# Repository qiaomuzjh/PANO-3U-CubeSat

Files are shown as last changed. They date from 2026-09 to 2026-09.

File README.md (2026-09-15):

# 🛰️ PANO-3U CubeSat | 双鱼眼全景立方星 — 全套开源设计制造文件包

**3U CubeSat · 500 km SSO · 360°×180° dual-fisheye panoramic imaging · Full open-source design & manufacturing package**

> 一颗可以在车库里造出来的卫星:从需求规格、GB 生产图纸、参数化 STEP 模型、KiCad 工程、
> BOM/工艺/检验试验规范,到飞行操作手册与发射场安全数据包——全部开源。

**License: CC BY-NC 4.0** (署名-非商业性使用) · Author / 作者:**张嘉豪 (Zhang Jiahao)**

---

## ✨ 任务概览 / Mission

| 项目 | 规格 |
|---|---|
| 构型 | 3U(100×100×340.5 mm),Cal Poly CDS Rev.14,P-POD 兼容 |
| 任务 | 双鱼眼侧面对置 360°×180° 全景成像,输出 5760×2880 |
| 载荷 | 2× Sony IMX477 + M12 鱼眼 f1.4/F2.4 FOV≥195°(等距投影) |
| 视频 | 4K30(CAM0)+ 2.8K30(CAM1),双机硬同步 <1 ms |
| 轨道 | 500 km SSO(i=97.4°),设计寿命 ≥1 年 |
| 数传 | UHF 437 MHz,GFSK 57.6 kbps(裕量 10.7 dB),AX.25/KISS |
| 电源 | 72 片太阳阵 18.4 W BOL,4 通道 MPPT,2S2P 49 Wh |
| 姿态 | B-dot 消旋(17.3°/s→2°/s @2.3 h)+ 磁强计粗定姿 ±5° |
| 质量 | 2.83 kg(含 20% 裕量)| 结构基频 611 Hz | 全 SF≥28 |

## 📁 仓库结构 / Repository Layout

```
00_包总览/          标准符合性索引 · 配置基线 · 需求追溯矩阵 · 文件总索引
01_系统设计文件/    需求规格 · 设计说明书 · ICD · 电子规格书 · 结构/热/可靠性/EMC/FMEA
02_评审与质量/      设计评审 · 数据一致性核查 · 模型与数据检验
03_生产图纸_GB23页/  ★ 23 张 GB 机械制图生产图纸(PDF/PNG/SVG,含完整尺寸链与形位公差)
04_三维模型_STEP/    ★ 15 个参数化重建实体(零件 + 整星装配,AP214)
05_电气设计_KiCad/   板框模板 ×4 + 投板核对清单
06_物料清单/         PL-001 零件明细表(关键件分级)+ BOM v2 采购清单
07_生产与装配工艺/   制造总方案(里程碑)· 装配工艺规程(A1-A12 工序卡)
08_检验与试验/       检验与试验规范(GEVS 振动 + TVAC 热真空)
09_软件/             载荷软件(CM4)· OBC 固件(STM32)· 地面站(Python)+ 发布说明
10_发射与运营/       飞行操作手册 · 地面站手册 · 离轨方案 · 发射场安全数据包
99_归档/             原始设计资料 + 已替代示意图册(禁止用于生产)
```

## 🚀 快速开始 / Quick Start

- **想看这颗星长什么样** → `03_生产图纸_GB23页/PDF`(23 页)或 `04_三维模型_STEP/装配`
- **想复刻/教学** → `00_包总览/STD-000`(标准对照)→ `REQ-001`(需求)→ `07`(工艺)→ `08`(试验)
- **想学卫星工程** → 从 `SPC-001 设计说明书` 入手,配合 `ANA-001 仿真报告` 与 `TRC-001 追溯矩阵`
- **要发射?** → 完成 `REV-001` 开放项 C1-C6,按 `SAF-001` 对接发射商

## 📐 标准体系 / Standards

Cal Poly **CDS Rev.14** · NASA **GSFC-STD-7000B (GEVS)** · **NASA-STD-7001A** ·
**SpaceX Rideshare PUG** · **ECSS** E-ST-10-03C / Q-ST-30-11C · **GJB** 1027A / 151B / Z 299C / Z 35 ·
**ISO 24113**(碎片减缓)· **ITU/IARU**(频率协调)· UN 3481(电池运输)
→ 逐项对照见 `00_包总览/STD-000`

## ⚠️ 免责声明 / Disclaimer

所有数值为设计/仿真值;本包为教学与研究用途,飞行应用必须完成文档中列出的开放项
(FEA 复核、镜头实测、热真空试验、软件联调、频率许可),并通过发射商安全评审。
本作品按"现状"提供,不附带任何担保。

## 📄 许可证 / License

**CC BY-NC 4.0**(署名-非商业性使用 4.0 国际)
- ✅ 自由共享、修改、二次创作(教学/研究/个人)
- ❌ 不得用于商业目的
- 📌 必须署名:张嘉豪 及本仓库链接,并标注修改
- 完整文本见 [LICENSE](LICENSE) · [NOTICE](NOTICE)

Copyright © 2026 张嘉豪 (Zhang Jiahao)

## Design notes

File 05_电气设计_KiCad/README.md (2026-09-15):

# PANO-3U KiCad 工程 README(v2 / 投产核对版)

**版本:v2 / 2026-09** | KiCad 7.0+ 打开 `PANO-3U.kicad_pro`
**本版修正(相对 vB README):**
1. ~~TPS2553×4 电子保险丝~~ → **U20 = TPS2557(CM4 支路 3 A),U21-U23 = TPS2553**(原理图 vB 已正确,本 README 旧文案有误,已勘误);
2. 数传默认速率 **57.6 kbps**(链路裕量 10.7 dB;9.6 kbps 为备份速率)——固件 comm.c 默认参数同步修改;
3. 新增 `板框模板/`:四种板的 PCB-000 外形(.kicad_pcb,Edge.Cuts 已绘 90×90 四角 45° 切口 + 4×Ø3.2 安装孔),Layout 直接导入。

## 工程结构
| 文件 | 内容 |
|---|---|
| `PANO-3U.kicad_pro` | 工程文件 |
| `PANO-3U.kicad_sch` | 根图(层次化入口) |
| `eps.kicad_sch` | E8 EPS(U1-U4 LT3652 MPPT、U6 TPS54331、U20 TPS2557、U21-23 TPS2553、INA226×4) |
| `obc.kicad_sch` | E7 OBC(STM32F405、TPS3823、W25Q128、DS3231、MPU-9250、QMC5883L、DRV8837×3) |
| `comm.kicad_sch` | E9 UHF(Si4463、RA07H4452M 1W PA、PE4259、SAW、TCXO 30MHz) |
| `cm4_carrier.kicad_sch` | E2 CM4 载板(DF40C-100DP、双 22P CSI、TPS22965、microSD) |
| `PANO-3U.kicad_sym` | 项目符号库(18 个自定义符号) |
| `板框模板/` | PCB-000 外形模板 ×4(本版新增) |

## 投板前核对清单(必须逐条签署)
1. **自定义符号引脚映射**(18 个符号,引脚号为逻辑编号):
   - LT3652 → MSOP-12EP 实际封装(占位 DFN16 必须改);
   - STM32F405RGT6 → LQFP-64 实际引脚号;
   - RA07H4452M / PE4259 / Si4463 模块逐脚核对;
2. R/C/L/D/连接器使用 KiCad 官方库,天然正确;
3. 运行 **ERC** 全绿后再 Layout;
4. 电源完整性:5V 走线 ≥0.5 mm(或敷铜),VBAT ≥0.8 mm;MIPI 差分 100Ω 等长 ±0.5 mm;
5. **U20 必须 TPS2557**:BOM/位号/丝印三处核对,防止与 TPS2553 混贴(两者封印相似);
6. CM4 双相机:CAM1 为 2-lane,相机 2 的 D2/D3 已断开;4K30 带宽实测不足则切换 CM5/USB3 备选;
7. 板框以 `板框模板/*.kicad_pcb`(PCB-000,与生产图纸册 P15 一致)为准;
8. 网表与 `BOM v2.xlsx`(E 系列)、`ELE-002 规格书` 三处一致后方可投板。

## 与其他文件的协调
原理图网络名/位号 ↔ BOM v2(E 系列)↔ ELE-002 规格书 逐条对应;改动任何一处四处同步
(另两处:生产图纸册 ELE-403 器件布局、固件信号命名)。

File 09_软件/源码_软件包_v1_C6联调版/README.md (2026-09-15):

# PANO-3U 软件包

版本 B / 2026-09 — 双鱼眼全景立方星完整软件系统

## 组成

```
软件包/
├── docs/通信协议规范.md        板间链路 + UHF上下行 帧格式/指令/错误码
├── payload_cm4/               ★ 星上载荷软件 (CM4, Python3, Raspberry Pi OS)
│   ├── main.py                主程序/状态机/systemd服务入口
│   ├── camera.py              双鱼眼同步采集 (picamera2, RAW+H.265)
│   ├── stitch.py              全景拼接核心 (等距投影+重叠区加权融合)
│   ├── storage.py             文件登记/分块/断电保护/空间回收
│   ├── link.py                OBC链路 (HDLC帧+CRC16, 流式解码)
│   ├── config.py              参数表 (可在轨更新)
│   └── tests/                 6项单元测试 (全部通过)
├── obc_firmware/              ★ OBC飞控固件 (STM32F405, C/HAL/FreeRTOS)
│   └── Core/{Src,Inc}/        main/fsm/adcs/comm/payload_mgr/驱动/日志
└── ground_station/            ★ 地面站 (Python3)
    ├── ground_station.py      主控 (对接Direwolf KISS)
    ├── receiver.py            AX.25解析 + 下行包解码
    ├── image_assemble.py      图像分块重组/断点续传/断电恢复
    ├── stitch_ground.py       地面精拼接 (特征匹配+多频段融合)
    ├── calibrate.py           出厂标定工具 (旋转棋盘格法)
    └── pass_predict.py        过境预测 (TLE+SGP4)
```

## 部署

**CM4 星上**：
```bash
sudo cp -r payload_cm4 /opt/pano3u/
sudo systemctl enable /opt/pano3u/pano3u-payload.service
# calibration.json 由出厂标定生成后放入 /opt/pano3u/
```

**OBC**：见 `obc_firmware/README.md`（CubeMX/PlatformIO 构建）。

**地面站**（Linux + RTL-SDR 或 UHF 电台声卡）：
```bash
pip install opencv-python numpy skyfield pyserial
direwolf -t 0 -r 48000 -   # 或接电台声卡
python3 ground_station/ground_station.py --kiss 127.0.0.1:8001
```

## 研制测试顺序

1. `pytest payload_cm4/tests/` —— 协议/存储/拼接单元测试（PC 上跑）
2. 桌面联调：CM4 实物 + USB-串口 ↔ 跑通 OBC 协议的 PC 模拟器
3. 双相机标定：`calibrate.py` 生成 `calibration.json`
4. 星地链路拉距：SDR 发信标 → 地面站解码验证
5. 整星联试：振动/热真空后复测拍摄与下传

## 关键性能

- 拍照→全景图生成：约 8 s（5760×2880，含双 RAW 采集）
- 视频：双路 4K30 H.265，码率 25 Mbps/路
- 下行：单过境 ≈400 KB（9.6 kbps×8 min×70% 效率），5 MB 全景图约 12 个过境
- 断点续传：块级位图 + 选择重传，支持跨过境断点

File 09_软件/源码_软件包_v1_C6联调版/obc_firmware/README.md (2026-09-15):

# OBC 固件构建说明

## 工具链
- STM32CubeMX 6.x (生成HAL骨架) + arm-none-eabi-gcc
- 或 PlatformIO: `platform = ststm32`, `board = genericSTM32F405RG`

## 目录
```
Core/Src/
  main.c          主程序+任务
  obc_fsm.c       模式状态机
  adcs.c          B-dot消旋
  comm.c          AX.25+下行队列
  payload_mgr.c   CM4协议+拍摄计划
  link_proto.c    板间帧编解码
  drivers.c       QMC5883L/MPU9250/INA226/DS18B20/热控/天线
  misc_drivers.c  DRV8837/看门狗/W25Q128日志
Core/Inc/         对应头文件 (位号/寄存器地址与电子系统规格书一致)
```

## 构建
```bash
# CubeMX方式: 用 PANO-3U.ioc 生成工程后替换Core/Src
arm-none-eabi-gcc -mcpu=cortex-m4 -mthumb -mfpu=fpv4-sp-d16 -mfloat-abi=hard \
  -O2 -DUSE_HAL_DRIVER -DSTM32F405xx ...
# PlatformIO方式:
pio run -e obc
```

## 关键配置
- FreeRTOS: 4任务 (comm>adcs>hk>payload), 堆栈见main.c
- HSE 8MHz → PLL → 168MHz, SysTick 1kHz
- UART1=9600(通信板), UART2=115200(CM4), 均DMA+空闲中断
- Flash: 前64KB bootloader(预留IAP), 应用从0x08010000

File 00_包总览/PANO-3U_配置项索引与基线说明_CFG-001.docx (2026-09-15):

PANO-3U 双鱼眼全景立方星

(3U CubeSat · 500km SSO 全景成像任务)

配置项索引与基线说明

配置项清单 · 图样目录 · 基线定义 · 替代关系

文档编号 | PANO-3U-CFG-001
版本 | A(功能基线→生产基线)
编制日期 | 2026-09
编制 / 审核 / 批准 | / /
分发 | 制造 / 质量 / 采购 / 试验

# 1 基线定义

①功能基线 = REQ-001(SPC-001 §2);②分配基线 = 各分系统设计文件(ELE-002/STR-001/THR-001/REL-001/EMI-001);③生产基线 = 生产图纸册 23 页(A 版)+ BOM v2 + DXF v4 + STEP v2 + KiCad v2;④软件基线 = SW-001 标识的版本。任何基线更改走 REV-001 行动项流程并同步SPC-001 ↔ 图纸 ↔ BOM v2(四处同步原则)。

# 2 配置项清单(设计与制造)

配置项 | 版本/基线 | 形式 | 状态
生产图纸册 P1–P23 | A | PDF/PNG/SVG(A3) | 现行(生产放行)
DXF 加工文件 ×13 | v4 | DXF | 现行(与图纸一致,QA-001 D1)
STEP 模型 ×15(含整星装配) | v2 | STEP AP214 | 现行(MDV-001 检验通过)
KiCad 工程(4 板)+板框模板 | 原理图 vB / 板框 v2 | kicad_sch/kicad_pcb | 现行(ERC/符号映射见核对清单)
BOM v2 / PL-001 零件明细表 | v2 / A | xlsx | 现行
管理文件 MFG-001/QA-001/WI-001/QT-001 | v1.0 | docx | 现行
设计文件 SPC/REQ/ICD/ELE/STR/ANA/THR/REL/EMI/FMEA/REV/STD/OPS/DEB/GND/SAF | A/B | docx | 现行
软件(载荷/固件/地面站) | 见 SW-001 | 源码+构建物 | C6 联调版
仿真数据 CSV ×11 | v1 | csv | ANA-001 引用,随包归档

# 3 图样目录(Drawing List)

图号/页 | 名称 | 版本 | 状态
P1 ASM-001 | 总装配图 | A | 现行
P2–P13 | MEC-101/102/103A/103B/104/105/106/107/111/108/109/110 零件图 | A | 现行
P14 PLD-201 | 相机传感器板 | A | 现行
P15 PCB-000 | 电路板外形图(通用) | A | 现行
P16 BAT-001 | 电池舱组件装配图 | A | 现行
P17 PLD-001 | 相机模组组件装配图 | A | 现行
P18 ELE-001 | 电气堆栈组件装配图 | A | 现行
P19 SOL-001 | 太阳阵铺贴图 | A | 现行
P20 ANT-001 | 天线组件装配图 | A | 现行
P21 SEP-001 | 分离开关与 RBF 机构装配图 | A | 现行
P22 WIR-001 | 线束图与下线表 | A | 现行
P23 ENV-001 | 整星包络检验图 | A | 现行

# 4 替代关系(旧文件处置)

旧文件 | 处置 | 替代
《3U 全景立方星全套图纸 v3/v4》PDF(18 页)与《总装图纸 v4》(3 页) | 归档(01_原始设计资料) | 生产图纸册 23 页(A 版)
《线稿示意图册》22 页(ASM-000~WIR-701 示意版) | 降级为“参考图册”,仅供装配示意,不得用于加工 | 生产图纸册 23 页
原 BOM 清单 v1 | 归档 | BOM v2 / PL-001
原 md 格式说明书/规格书/评审/结构/仿真报告 | 归档 | SPC-001/ELE-002/REV-001/STR-001/ANA-001
原 STEP 模型(简化版) | 归档 | STEP v2(参数化重建,MDV-001 检验)

PANO-3U-CFG-001 配置项索引与基线说明 A(功能基线→生产基线)

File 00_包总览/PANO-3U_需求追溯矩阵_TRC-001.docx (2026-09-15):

PANO-3U 双鱼眼全景立方星

(3U CubeSat · 500km SSO 全景成像任务)

需求追溯矩阵

SYS/分系统需求 → 图纸/模型/软件 → 工序 → 验证

文档编号 | PANO-3U-TRC-001
版本 | A(需求→设计→制造→验证 全链路)
编制日期 | 2026-09
编制 / 审核 / 批准 | / /
分发 | 制造 / 质量 / 采购 / 试验

# 1 追溯矩阵

需求 | 设计证据 | 制造证据 | 验证证据 | 状态
SYS-01 包络 | P1/P23;STEP ASM-001 | WI-001 A12 | QT-001 §4.2(检具) | ✅
SYS-02 质量 | BOM v2;STEP 体积(MDV-001 §1) | A12 称重 | QT-001 §4.4(≤2.9 kg) | ✅
SYS-03 频率 | P2/P3/P6;STEP 导轨 | A1/A2/A8 | QT-001 §5.1(衰减<5%) | ✅(FEA=C1)
SYS-04 结构环境 | P2/P3/P6;STR-001 | KCP-5 marking | QT-001 §5.1(GEVS) | ✅
SYS-05 全景 | P17/P19;SW 载荷 | A6 锁焦(KCP-3) | 出厂标定+拼接验证 | ✅
SYS-06 视频 | ELE-002 §4;SW 载荷 | A3 堆栈/A7 FPC | C6 实测 | △(C6)
SYS-07 轨道 | ANA-001 S1 | — | A | ✅
SYS-08 测控 | P18/P20/P22;ELE-002 §5 | A11 敷设;WIR-001 | QT-001 §4.12 拉距 | △(B 阶段)
SYS-09 姿态 | P18;ELE-002 §3;SW 固件 | A3;W11 下线 | ANA-001 S5 + 在轨 | ✅(A)
SYS-10 能源 | P19;THR-001;BOM E15-E20 | A5(KCP-8)/A10(KCP-4) | QT-001 §4.7 + TVAC | ✅(A)
SYS-11 热控 | THR-001;BOM E17/E34 | A5 MLI/加热 | QT-001 §5.2 TVAC | △(C4)
SYS-12 发射安全 | P21/P3;SEP-001 | A9 停检点(KCP-7) | QT-001 §4.6 四状态 | ✅

# 2 追溯纪律

需求新增/变更:REQ-001 变更单 → 设计文件与图纸同步 → 本矩阵更新 → QT-001 验证项更新;矩阵每阶段评审(REV-001)复核一次,未闭环项自动成为 REV 行动项。

PANO-3U-TRC-001 需求追溯矩阵 A(需求→设计→制造→验证 全链路)

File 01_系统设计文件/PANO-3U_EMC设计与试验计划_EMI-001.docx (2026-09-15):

PANO-3U 双鱼眼全景立方星

(3U CubeSat · 500km SSO 全景成像任务)

EMC 设计与试验计划

设计与安装规则 · 自兼容试验 · 频率协调

文档编号 | PANO-3U-EMI-001
版本 | A(对照 GJB 151B / MIL-STD-461G)
编制日期 | 2026-09
编制 / 审核 / 批准 | / /
分发 | 制造 / 质量 / 采购 / 试验

# 1 EMC 设计控制

①电源:各支路限流+输入 TVS;DC-DC 开关频率远离 UHF 中频;母线入口 π 滤波;②结构:单点接地(结构地经 1 MΩ+10 nF 浮接),搭接电阻<2.5 mΩ;③信号:MIPI 差分 100Ω 屏蔽,敏感器线远离 PA/磁力矩器;④磁:磁力矩器工作与磁强计采样分时(QMC 采样窗口避开 PWM 沿);⑤PA 发射时 OBC/相机由屏蔽罩+软件滤波兜底。

# 2 试验计划(阶段 B,对照 GJB 151B / MIL-STD-461G)

项目 | 方法参照 | 限值/判据
CE102 电源传导发射 | GJB 151B CE102 | 母线传导≤曲线限值;无开关噪声超标
RE102 电场辐射发射 | GJB 151B RE102 | PA 关/开对比;除载波外无杂散超标
CS115/116 脉冲与传导敏感 | GJB 151B | 不引起复位/数据错误
RS103 电场辐射敏感 | GJB 151B | 50 V/m 下功能正常(过顶裕度内)
自兼容专项 | PA 发射时 IMU/磁强计/温度读数比对 | 读数无跳变或可软件滤波恢复
整星星地拉距 | 发射场/校园 | 57.6 kbps 误包率<1%(10.7 dB 裕量)

# 3 频率协调

下行 437.0 MHz 处于业余卫星频段(435-438 MHz);发射前完成 IARU 频率协调申请与中国无线电管理机构(或发射商要求之牌照方)许可;上行采用业余段对应频点;发射前提交调制参数/带宽/EIRP/轨道给协调方存档。

PANO-3U-EMI-001 EMC 设计与试验计划 A(对照 GJB 151B / MIL-STD-461G)

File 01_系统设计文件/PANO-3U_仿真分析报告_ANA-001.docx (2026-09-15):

PANO-3U 双鱼眼全景立方星

(3U CubeSat · 500km SSO 全景成像任务)

仿真分析报告

质量/轨道/能源/热/结构/ADCS/链路/光学(S0–S7)

文档编号 | PANO-3U-ANA-001
版本 | A(对应设计版本 C)
编制日期 | 2026-09
编制 / 审核 / 批准 | / /
分发 | 制造 / 质量 / 采购 / 试验

# 0 方法声明

全部仿真为 Python 数值计算(轨道:二体+J2;磁场:倾斜 11.5° 偶极;热:6 节点集总,5 s 步长;结构:一维梁 FE;姿态:四元数动力学,dt=0.5 s),输入取自版本 C 设计文件。本报告用于方案定值与验证,正样阶段以高保真工具(STK/IGRF/ESATAN/ANSYS)复核(开放项)。

# S0 质量特性

指标 | 数值 | 备注
干质量 | 2 359 g | 25 项分部件几何重建(旧 BOM 估算 1 730 g 低估 27%)
发射质量 | 2 831 g(+20%) | CDS 上限 4 800 g,裕量 41%
质心 | (0.0, −0.2, 146.7) mm | 低于几何中心 23.6 mm(重力梯度有利)
惯量 | Ixx=0.0168/Iyy=0.0173/Izz=0.00271 kg·m² | —

# S1 轨道与过顶

500 km SSO(i=97.40°,T=94.5 min),每日 15.2 轨;最坏日食 β=0 时 35.7 min/轨(37.8%),β≥65° 时降至 14.5 min。北京站 7 天过顶 20 次(2.9 次/天),平均 6.2 min、最大 7.3 min。

# S2 能源(最坏 β=0,EOL 0.90,MPPT 0.95)

项 | 结果
单轨平均发电 | 3.41 W → 日 81.9 Wh
日耗电 | 30 Wh(4 次拍摄+过顶数传占空)
裕量 | 2.73×(β 0°~60° 扫描均 ≥2.7×)
7 天时域 SOC | 80%~100%,最低 DoD 20%(限 80%)✅

# S3 热(六节点集总,48 h)

工况 | 核心 | 面板 | 电池 | 判定
热(全日照+载荷 2W) | 15~20°C | 15~19°C | 15~20°C | ✅
冷(原设计:裸装+2W) | −24~3°C | −26~3°C | −21~6°C | ✗ 低于充电禁限
冷(修订:MLI+3W) | −20~8°C | −22~7°C | −12~+8°C | △ 占空 79%,TVAC 收口

设计修订已回写:电池包 MLI、加热 2→3 W、LT3652 NTC 0°C 禁充;BOM v2 已同步(QA-001 A2/A3)。

# S4 结构

梁 FE:f1=611 Hz;随机 GEVS:Miles 39.2 gRMS(3σ=118 g);准静态 10 g。裕度:导轨压应力 SF=76/屈曲≫100/F2 剪切 28/电池支架 36/相机支架 52(详 STR-001)。

# S5 ADCS(B-dot 消旋)

初始 10°/s/轴(|ω|=17.3°/s)→ 2.3 h 降至 ≤2°/s,24 h 后 0.13°/s;磁偶限幅 0.2 A·m²;全景任务(≤2°/s)成立,无需反作用轮。

# S6 通信链路

速率 | 灵敏度 | 最低裕量 | 日吞吐 | 判定
9.6 kbps | −120 dBm | 18.7 dB | 0.8 MB | 备份速率
57.6 kbps(默认) | −112 dBm | 10.7 dB | 4.6 MB | ✅ 35 快视图/天
115.2 kbps | −109 dBm | 7.7 dB | 9.2 MB | 可选

整星级发现:4K 视频(375 MB/min)物理上无法经 UHF 下传;存 512 GB 卡仅下抽帧;S 频段升级(1 Mbps→85 MB/天,+¥2 500)列为选装。

# S7 光学

等距投影角分辨率 15.8 px/°(全视场恒定),拼接输出 5760×2880=16.0 px/° ✅;重叠环带 82.5°~97.5°(13% 全球面,≥8° 匹配下限 1.9×)✅;GSD:星下 0.55 km/px,60° 离轴 2.21 km/px(辅助功能)。

# S8 汇总判定

项 | 结论
质量/包络 | ✅ 2.83 kg,CDS 合规
轨道/过顶 | ✅ 2.9 次/天
能源 | ✅ 2.73×,SOC≥80%
热 | △ 修订后满足(MLI+3W+NTC),TVAC 收口
结构 | ✅ f1=611 Hz,SF≥28
ADCS | ✅ 2.3 h 消旋
链路 | △ 57.6 kbps 满足运营;视频需 S 频段选装
光学 | ✅ 指标闭环

CSV 原始数据(11 个文件)随原始资料归档。

PANO-3U-ANA-001 仿真分析报告 A(对应设计版本 C)

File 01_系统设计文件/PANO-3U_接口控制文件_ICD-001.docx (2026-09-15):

PANO-3U 双鱼眼全景立方星

(3U CubeSat · 500km SSO 全景成像任务)

接口控制文件(ICD)

机械 / 电气 / 射频 / 地面段 四类接口

文档编号 | PANO-3U-ICD-001
版本 | A
编制日期 | 2026-09
编制 / 审核 / 批准 | / /
分发 | 制造 / 质量 / 采购 / 试验

# 1 机械接口(M-ICD)

接口 | 定义 | 公差/要求
星-P-POD | 4 导轨 8.5×8.5×340.5;中心距 91.5×91.5;端板 100×100 分离面 | 导轨 0/−0.05;共面度≤0.1;分离弹簧行程按 CDS
星-相机 | 侧板窗 Ø26+0.1/0;镜头外伸 6.0(限 6.5);三级定位链同轴≤Ø0.05 | 窗位 (170±0.05, 41.5±0.05)
星-电池 | MEC-106 抱箍内腔 37×23.4;18650 Ø18.6×65.4 | 内阻配对≤20 mΩ 差
星-太阳阵 | 贴片区 3-92×71,起点 14/121/228,边距 6 | 贴片位置±0.5
星-天线 | MEC-109 装 +Z 端板 ±Y 边;卷收态不超包络 | 臂长 344±2

# 2 电气接口(E-ICD)

## 2.1 J1 堆栈总线(全 40 位)

Pin | 信号 | Pin | 信号 | Pin | 信号 | Pin | 信号
1 | GND | 2 | GND | 3 | VBAT | 4 | VBAT
5 | +5V | 6 | +5V | 7 | +3V3 | 8 | +3V3
9 | I2C1_SDA | 10 | I2C1_SCL | 11 | UART_OBC_TX | 12 | UART_OBC_RX
13 | UART_CM4_TX | 14 | UART_CM4_RX | 15 | CAN_H | 16 | CAN_L
17 | DEPLOY_EN | 18 | ANT_STAT | 19 | SAFE_MODE | 20 | WD_KICK
21 | MAG_X_PWM | 22 | MAG_Y_PWM | 23 | MAG_Z_PWM | 24 | HEAT_EN
25 | SW_STAT | 26 | PAYLOAD_EN | 27-40 | GND/预留

## 2.2 外接连接器

代号 | 连接器 | 走向 | 引脚定义
J1 | 2×20P 车针 | 四板堆栈 | 上表
J2 | JST-XH2P | 分离开关链→EPS | Pin1=SW 链+,Pin2=−
J3 | JST-XH2P | RBF 座→EPS | 同上
J4-J7 | JST-XH2P | ±Y/±X 太阳阵→EPS | Pin1=+,Pin2=−
J8 | JST-XH2P | EPS→CM4 5V | Pin1=+5V,Pin2=GND
J9 | JST-SH6P | EPS→加热+温控 | 加热±×2、温控×2、预留
J12 | SMA-KY | COMM→天线(经巴伦) | 50Ω

## 2.3 功率分配

支路 | 限流 | 负载
CM4+相机 | 3 A(TPS2557) | CM4 5V 输入;拍摄峰值 9.45 W
OBC | 1 A(TPS2553) | STM32+敏感器 ≈0.4 W
PA | 1.5 A(TPS2553) | UHF 发射 3.75 W 输入
加热 | 1 A(TPS2553) | 3 W×2(占空 79%)

# 3 射频接口(RF-ICD)

项 | 定义
频率 | 437.0 MHz(业余卫星段,以 IARU 协调为准)
调制/速率 | GFSK;57.6 kbps(默认)/9.6 kbps(备份)
EIRP | ≈29 dBm(1 W PA − 线损 + 天线增益)
多普勒 | ±10 kHz(500 km SSO,过顶补偿)
极化/指向 | 线极化;全向偶极,过顶无需精确指向
禁射 | 分离后 DEPLOY_DELAY(30/45 min 按发射商)

# 4 地面段接口(G-ICD)

项 | 定义
站址 | 北京(40°N,116°E),仰角门限 10°,过顶 2.9 次/天,平均 6.2 min
设备 | 12 dBi 八木+旋转器+RTL-SDR/电台+Direwolf KISS 127.0.0.1:8001
数据流 | KISS→receiver.py 解码→image_assemble 重组→stitch_ground 拼接
测控协议 | AX.25 UI 帧;上行指令双重确认+错误码(通信协议规范.md)

PANO-3U-ICD-001 接口控制文件(ICD) A

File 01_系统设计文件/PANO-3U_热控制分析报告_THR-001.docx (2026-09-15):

PANO-3U 双鱼眼全景立方星

(3U CubeSat · 500km SSO 全景成像任务)

热控制分析报告

工况 · 修订定值 · TVAC 判据

文档编号 | PANO-3U-THR-001
版本 | A(六节点集总网络)
编制日期 | 2026-09
编制 / 审核 / 批准 | / /
分发 | 制造 / 质量 / 采购 / 试验

# 1 模型与假设

六节点集总网络:核心(OBC/EPS/CM4 组合体)、+Y/−Y 面板(太阳片)、+X/−X 面板、电池组;步长 5 s、仿真 48 h。辐射基准:阳极氧化 ε≈0.85(黑色)/0.1(抛光);导热路径:CM4→导热垫(1 mm,6 W/m·K)→散热块→铜柱→端板;电池组→支架→侧板。热耗:待机 0.78 W / 拍摄 9.45 W / 数传 3.75 W;外热流按 500 km SSO β 角扫描。

# 2 工况与结果

工况 | 核心 | 面板 | 电池 | 判定
热工况(全日照+载荷 2 W) | 15~20°C | 15~19°C | 15~20°C | ✅ 无过热
冷工况(最大日食+SAFE,原设计裸装+2 W) | −24~3°C | −26~3°C | −21~6°C | ✗ 低于 0°C 充电禁限
冷工况(修订:MLI+3 W 加热) | −20~8°C | −22~7°C | −12~+8°C | △ 占空 79%,日照段恢复充电

# 3 设计修订(已回写设计与 BOM v2)

①电池组外覆 MLI 多层隔热(双面镀铝聚酯 10 层,有效发射率≈0.03),引线穿孔衬套;②加热膜 2→3 W×2(聚酰亚胺,5 V),与 KSD9700(5°C 闭合/8°C 断开)硬件串联;③LT3652 NTC(10 kΩ B=3380,贴电池)配置 0°C 充电禁止;④镜头侧日照局部可超 +45°C:镜座/镜头选耐温材料,TVAC 验证(开放 C4)。

# 4 TVAC 验收判据(试验阶段 B)

项 | 判据
压力 | ≤1×10⁻³ Pa
循环 | −20~+50 °C ×4 循环,高低温各保持 2 h(变化率<1°C/10 min 判稳定)
电池温度 | 冷工况 ≥0°C(充电允许)或证实禁充逻辑生效;热工况 ≤+45°C
功能 | 每个高温/低温平台完成一次双机拍摄;数传一次
后检 | 复压后外观/绝缘≥10 MΩ/紧固 marking 复查

PANO-3U-THR-001 热控制分析报告 A(六节点集总网络)

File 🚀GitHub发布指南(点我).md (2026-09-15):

# 🚀 GitHub 发布操作指南(张嘉豪专用,三选一)

本机环境:**未安装 git**,本机无你的 GitHub 凭证(QQ 浏览器的登录态无法传给命令行),
所以仓库内容我已 100% 备好在 `桌面\PANO-3U-CubeSat`,你只需按下面三种方式**任选其一**完成发布。

推荐顺序:**方式 A(GitHub Desktop,最简单)> 方式 B(网页直传)> 方式 C(命令行)**

---

## 方式 A:GitHub Desktop(推荐,10 分钟)

1. 下载安装 **GitHub Desktop**:https://desktop.github.com
2. 打开 GitHub Desktop → `File` → `Add local repository` → 选择
   `C:\Users\qiaomu\Desktop\PANO-3U-CubeSat`
   → 会提示"not a repository",点 `Create a Repository`:
   - Name: `PANO-3U-CubeSat`
   - 勾选 "Keep this code private" **不要勾**(要开源)→ `Create Repository`
3. 顶部菜单 `Repository` → `Push` → 首次会弹登录:
   - `Sign in to github.com` → 浏览器授权(你 QQ 浏览器已登录,直接点 Authorize)
   - 若浏览器默认不是 QQ 浏览器:在 GitHub Desktop 设置里 `Options → Advanced`
     选择默认浏览器,或复制授权链接到 QQ 浏览器打开
4. 推送前先去网页建仓库:浏览器打开 https://github.com/new
   - Repository name: `PANO-3U-CubeSat`
   - 选 **Public** → 不要勾任何初始化选项(README/LICENSE 都已备好)→ `Create`
   - 回到 GitHub Desktop → `Repository` → `Push` → `Publish repository`
     (取消勾选 "Keep this code private")→ 完成 ✅

---

## 方式 B:网页直传(零安装,~5 分钟)

1. 浏览器打开 https://github.com/new
   - Name: `PANO-3U-CubeSat`;选 **Public**;**全部取消勾选**(README/LICENSE/gitignore 我已备好)→ `Create repository`
2. 在新仓库页点 **"uploading an existing file"**
3. 把 `桌面\PANO-3U-CubeSat` 里的**全部内容**(不是文件夹本身)拖入上传框
   - ⚠️ 网页上传单文件限 25 MB、总数最多 100 个文件——
     本包 234 个文件超限,建议:先拖 00~10 的文件夹(共 ~200 个),
     `99_归档` 与 `09_软件/源码` 若提示过多,分 2-3 批拖入
4. 底部 Commit message 填 `PANO-3U 全套开源设计制造文件包 v1.0` → `Commit changes` → 完成 ✅
   (更省事还是用方式 A/C)

---

## 方式 C:命令行 git(装 Git 后最通用)

1. 安装 Git for Windows:https://git-scm.com/download/win(一路下一步)
2. **Win+R → `cmd`**,逐条执行(用户名/邮箱换成你的):

```bat
cd /d C:\Users\qiaomu\Desktop\PANO-3U-CubeSat
git init
git add .
git commit -m "PANO-3U 全套开源设计制造文件包 v1.0"
git branch -M main
```

3. **配置代理**(你挂了梯子,git 不走系统代理,必须单独配;端口看你梯子软件,
   Clash 默认 7890,v2rayN 默认 10809):

```bat
git config --global http.proxy  http://127.0.0.1:7890
git config --global https.proxy http://127.0.0.1:7890
git config --global user.name  "Zhang Jiahao"
git config --global user.email "你的GitHub邮箱"
```

4. 浏览器打开 https://github.com/new → Name: `PANO-3U-CubeSat` → Public →
   **取消勾选 README/LICENSE/gitignore** → Create

5. **用 PAT 登录推送**(命令行不能用浏览器登录态,需要令牌):
   - 打开 https://github.com/settings/tokens → `Generate new token (classic)`
   - 勾选 `repo` 权限 → 生成后**立即复制**(只显示一次)
   - 回到 cmd:

```bat
git remote add origin https://github.com/你的用户名/PANO-3U-CubeSat.git
git push -u origin main
```

   - 弹出登录窗口:用户名=你的 GitHub 用户名,密码=粘贴刚才的 **PAT 令牌**
   - 推送完成 ✅ 打开仓库页即可看到全部文件

---

## 📋 发布前最后检查(已替你核过)

- ✅ 无任何密钥/令牌/个人隐私信息(签署栏均为空白占位)
- ✅ 版权与署名:NOTICE/LICENSE 已写"张嘉豪 (Zhang Jiahao)",CC BY-NC 4.0 全文
- ✅ 频率/发射安全内容均为公开标准知识;地面站坐标仅到城市级
- ⚠️ 开源即公开:BOM 里的采购价格、地面站位置(北京)如介意可自行删除后推送
- ⚠️ NC 许可:GitHub 开源无碍;但 **CC BY-NC 不是 OSI 开源许可证**,严格说是
  "免费公开+非商用";若日后希望商用友好,可另加 `LICENSE-CODE`(GPL/MIT)双许可

## 建议仓库设置

- Description: `PANO-3U open-source 3U CubeSat — full design & manufacturing package (GB drawings / STEP / KiCad / docs) CC BY-NC 4.0`
- Topics: `cubesat` `satellite` `open-source-hardware` `space` `panoramic-camera` `step` `kicad`
- 若单文件超 25 MB 报错(不太会,最大 6.5 MB),或日后模型变大,再考虑 Git LFS

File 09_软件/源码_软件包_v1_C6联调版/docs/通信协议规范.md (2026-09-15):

# PANO-3U 通信协议规范

版本 B / 2026-09

## 1. 板间链路（OBC ↔ CM4 载荷计算机）

- 物理层：UART，115200 8N1，3.3V 电平，经堆栈总线 J1（Pin 13/14）
- 帧结构（HDLC 风格）：

```
[0x7E][CMD:1B][LEN:1B][PAYLOAD:0~255B][CRC16-CCITT:2B][0x7E]
转义: 载荷中出现 0x7E→0x7D 0x5E；0x7D→0x7D 0x5D
```

### 指令表（OBC→CM4）

| CMD | 名称 | 载荷 | 说明 |
|---|---|---|---|
| 0x01 | PING | — | 心跳，CM4 须 1s 内回 ACK |
| 0x02 | TIME_SYNC | uint32 epoch | 时间同步 |
| 0x03 | SHOOT | uint8 burst, uint16 interval_s | 全景拍照（连拍张数/间隔） |
| 0x04 | VIDEO_START | uint16 duration_s, uint8 fps | 开始全景视频 |
| 0x05 | VIDEO_STOP | — | 停止录像 |
| 0x06 | TIMELAPSE | uint16 interval_s, uint16 count | 延时摄影 |
| 0x07 | GET_STATUS | — | 查询载荷状态 |
| 0x08 | FILE_LIST | uint16 offset | 文件清单（分页） |
| 0x09 | FILE_PREP | uint32 file_id | 准备下传某文件（返回分块表） |
| 0x0A | SHUTDOWN | — | 载荷安全关机（OBC 随后断 PAYLOAD_EN） |
| 0x10 | PARAM_SET | key:1B + value:4B | 参数设置（曝光/增益/编码码率等） |

### 应答（CM4→OBC）

| CMD | 名称 | 载荷 |
|---|---|---|
| 0x81 | ACK | 原CMD + status |
| 0x87 | STATUS | 见下 |
| 0x88 | FILE_LIST_RESP | count + [file_id:4B, size:4B, ts:4B]×N |
| 0x89 | FILE_PREP_RESP | file_id, total_chunks:2B, chunk_size:2B, file_crc32:4B |

STATUS 载荷（24B）：mode:1B, cam0_ok:1B, cam1_ok:1B, temp0:int8, temp1:int8, disk_free_mb:uint16, vbat_mv:uint16, shooting:1B, pending_files:uint16, uptime_s:uint32, last_err:1B, reserved:6B

## 2. UHF 下行链路（星→地）

- 物理层：437 MHz，GFSK 9600 bps，AX.25 UI 帧（HDLC 封装由 Si4463+OBC 软件完成）
- AX.25 地址：源=NOCALL-11（星），目的=NOCALL-0（地面），PID=0xF0

### 下行包类型（AX.25 Info 字段首字节为类型）

| 类型 | 名称 | 结构 | 时机 |
|---|---|---|---|
| 0x01 | 信标遥测 | [type][seq:2B][OBC遥测32B][CM4 STATUS 24B][CRC32] | 每 30s 周期性 |
| 0x02 | 文件块 | [type][file_id:4B][chunk_no:2B][total:2B][data:N][CRC32] | 过境时连续发送 |
| 0x03 | 文件清单 | 同 FILE_LIST_RESP | 应地面请求 |
| 0x04 | 事件日志 | [type][ts:4B][code:1B][data:8B] | 异常/模式切换时 |

### 断点续传与选择重传

- 文件分块：每块 200 字节，块内 CRC32 校验；
- 地面站按 file_id 收块，记录已收位图；
- 过境结束时地面站通过上行（AX.25 命令帧，需执照操作）或下一过境首包发送**缺失块清单**（位图压缩），星上补发；
- 单文件最多支持 65535 块（≈13 MB），全景图压缩后约 5 MB ≈ 25000 块，一过境（8 min @9.6kbps 有效吞吐约 400 KB）约 12 个过境传完。

### 上行（地→星）

| CMD | 名称 | 说明 |
|---|---|---|
| 0x21 | REQ_MISSING | file_id + 位图偏移 + 缺失块列表 |
| 0x22 | SET_MODE | 强制模式切换（双重确认） |
| 0x23 | SCHEDULE | 拍摄计划表上传（最多 32 条：[epoch, cmd, param]） |
| 0x24 | PARAM_SET | 同板间 0x10 |

## 3. 错误码

0x00 OK；0x01 相机0故障；0x02 相机1故障；0x03 存储满；0x04 存储I/O错误；0x05 编码器错误；0x06 温度超限；0x07 参数非法；0x08 链路超时

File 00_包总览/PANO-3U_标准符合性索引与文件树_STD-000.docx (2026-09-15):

PANO-3U 双鱼眼全景立方星

(3U CubeSat · 500km SSO 全景成像任务)

标准符合性索引与文件树

航天机构与商业航天公司标准对照 · 全套文件树

文档编号 | PANO-3U-STD-000
版本 | A
编制日期 | 2026-09
编制 / 审核 / 批准 | / /
分发 | 制造 / 质量 / 采购 / 试验

# 1 适用标准与符合性对照

标准/文件 | 发布方 | 适用范围 | PANO-3U 符合性证据
CDS Rev 14.1 (2022-02) | Cal Poly CubeSat Program | 3U 构型/尺寸/质量/分离界面/材料/轨道 | P23 包络检验图;SEP-001 分离链;QA-001 D 核查
GSFC-STD-7000B (GEVS) | NASA GSFC | 随机/正弦/热真空鉴定与验收量级与方法 | QT-001 §5(14.1 gRMS 三向、TVAC 四循环);STR-001 输入
NASA-STD-7001A | NASA | 声振试验 | QT-001(小卫星按机械传递随机为主)
NASA-STD-8739.x | NASA | 焊接/装配工艺(Workmanship) | WI-001(烙铁温度/点胶/压接规则)
SpaceX Rideshare Payload User’s Guide | SpaceX | CubeSat 随机振动≥MPE、分离速度 0.3~1.0 m/s、L-30 交付、紧固件表 6-3 | QT-001 量级选取;OPS-001 LEOP 时序;SAF-001
ECSS-E-ST-10-03C | ESA | 试验分类与判据 | QT-001 试验矩阵
ECSS-Q-ST-30-11C | ESA | FMEA 方法 | FMEA-001(S/O/D 评分)
GJB 1027A-2005 | 中国军标 | 运载器/航天器试验环境 | QT-001 对照引用
GJB 151B-2013 | 中国军标 | EMC 发射与敏感度 | EMI-001
GJB/Z 35 / MIL-STD-975 | — | 元器件降额 | REL-001 降额表
ISO 24113 / IADC-02-01 | ISO/IADC | 轨道碎片减缓(25 年规则) | DEB-001
FCC 47 CFR §25.114(5 年离轨) | 美国 FCC | 美国牌照 LEO 卫星 5 年离轨 | DEB-001(按牌照方适用)
ITU 无线电规则 第 9 条 / IARU | ITU/IARU | 435-438 MHz 业余卫星频率协调 | ELE-002 §5;LIC 频率协调
UN 3481 / IATA DGR | UN/IATA | 锂离子电池随设备运输(电池 SoC≤30% 空运规则) | SAF-001 运输章节

# 2 全套文件树(编号体系)

编号 | 文件 | 状态
SPC-001 | 详细设计说明书(需求 SR/SYS、定值、预算、ICD 索引) | A 版 ✅
REQ-001 | 系统需求规格(全量需求+验证矩阵) | 本包
ICD-001 | 接口控制文件(机械/电气/射频/地面) | 本包
ELE-002 | 电子系统设计规格书 | B 版 ✅
STR-001 | 结构力学校核报告 | B 版 ✅
ANA-001 | 仿真分析报告(S0-S7) | A 版 ✅
THR-001 | 热控制分析报告 | 本包
REL-001 | 可靠性预计与降额设计 | 本包
EMI-001 | EMC 设计与试验计划 | 本包
FMEA-001 | 失效模式与影响分析 | A 版 ✅
生产图纸册 | 23 页 GB 图纸(P1-P23) | ✅(经加工方意见补标)
BOM v2 | 全级物料清单(修正+采购属性) | ✅
MFG-001/QA-001/WI-001/QT-001 | 生产/核查/工艺/试验 | ✅
OPS-001 | 飞行操作手册(LEOP+在轨+离轨) | 本包
GND-001 | 地面站运行手册 | 本包
DEB-001 | 轨道碎片减缓与离轨方案 | 本包
SAF-001 | 发射场安全数据包 | 本包
01_原始设计资料 | 原版文件与 KiCad/STEP/仿真 CSV 归档 | ✅

引用:CubeSat Design Specification Rev 14.1(Cal Poly,2022-02);GSFC-STD-7000B GEVS(NASA,2021);SpaceX Rideshare Payload User’s Guide;NASA CSLI《CubeSat 101》。

PANO-3U-STD-000 标准符合性索引与文件树 A

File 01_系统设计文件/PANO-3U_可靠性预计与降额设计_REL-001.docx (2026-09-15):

PANO-3U 双鱼眼全景立方星

(3U CubeSat · 500km SSO 全景成像任务)

可靠性预计与降额设计

元件计数法 · 降额表 · 单粒子对策 · 冗余设计

文档编号 | PANO-3U-REL-001
版本 | A
编制日期 | 2026-09
编制 / 审核 / 批准 | / /
分发 | 制造 / 质量 / 采购 / 试验

# 1 任务剖面与可靠性目标

任务剖面:500 km SSO,1 年,轨道 5 470 圈,日食占空 ≤37.8%,发射段环境 GEVS;目标:任务期末系统可靠度 ≥0.80(不含发射风险)。

# 2 元件计数法预计(依据 GJB/Z 299C / MIL-HDBK-217F 思路)

单板/组件 | 主要器件数 | 预计失效率(10⁻⁶/h) | 备注
E8 EPS | ≈120 | ≈8.5 | 功率器件降额后
E7 OBC | ≈95 | ≈4.2 | 含敏感器
E9 UHF | ≈80 | ≈5.0 | PA 高应力
E2 CM4 载板 | ≈60 | ≈3.0(不含 CM4 本体)
电池组件 | — | ≈2.0 | BMS+连接
机构(天线/开关/热刀) | — | ≈3.5 | 动作件按循环折算
整星合计 | — | ≈26(不含 CM4/相机本体) | CM4/相机按商质件,寿命试验覆盖

按 λ=26×10⁻⁶/h,1 年(8 760 h)串联可靠度 e^(−λt)≈0.80,达目标;CM4 与相机为商质件,依赖抽验与地面老化筛选(72 h 老炼)。

# 3 降额设计(依据 GJB/Z 35 / MIL-STD-975)

类别 | 降额要求 | 本项目实施
电容电压 | ≤50% 额定 | 钽电容按母线 2 倍选取
电阻功率 | ≤50% 额定 | 限流/采样电阻按 2 倍功率
晶体管电流 | ≤75% 额定 | AOD510/IRLML6344 按 2 倍余量
IC 结温 | ≤110°C(商用) | 热设计结温 ≤70°C
继电器/开关触点 | ≤50% 额定电流 | 微动开关 3 A 触点,回路≤0.8 A

# 4 单粒子效应(SEE)与冗余策略

COTS 器件在 500 km LEO(倾角 97.4°)主要为质子引发 SEU;TID 年剂量约 1-3 krad(Si),1 年任务远低于 30 krad 摸底限(开放 C3)。对策:参数表与固件镜像双备份(W25Q128+eMMC)、看门狗 30 s 复位链、SAFE 模式自动恢复、通信指令 CRC+重传;存储采用磨损均衡与坏块管理。

# 5 冗余设计汇总

功能 | 冗余/备份 | 切换方式
参数存储 | W25Q128 + eMMC 双份 | 上电 CRC 校验择优
天线释放 | 热刀×2 双刀 | DEPLOY_EN 重试序列
加热 | 硬件温控+软件使能双保险 | KSD9700 硬件串联
太阳充电 | 四通道独立 MPPT | 旁路二极管隔离故障面
时间基准 | DS3231 RTC + MCU 内部时钟 | 遥测比对

PANO-3U-REL-001 可靠性预计与降额设计 A

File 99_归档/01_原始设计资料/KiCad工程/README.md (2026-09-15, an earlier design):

# PANO-3U KiCad 工程 README

**版本 B / 2026-09**　|　KiCad 7.0+ 打开 `PANO-3U.kicad_pro`

## 工程结构

| 文件 | 内容 |
|---|---|
| `PANO-3U.kicad_pro` | 工程文件（双击打开） |
| `PANO-3U.kicad_sch` | 根图：4 块板的层次化入口 |
| `eps.kicad_sch` | E8 EPS 电源板（47 元件：LT3652×4 MPPT、LTC4412 理想二极管、TPS54331 5V/3A、TLV70233、TPS2553×4 电子保险丝、INA226×4 遥测） |
| `obc.kicad_sch` | E7 OBC 主控板（22 元件：STM32F405、TPS3823 看门狗、W25Q128、DS3231、MPU9250、QMC5883L、DRV8837×3） |
| `comm.kicad_sch` | E9 UHF 通信板（Si4463 模块 + RA07H4452M 1W PA + PE4259 收发切换 + SAW 滤波 + 30MHz TCXO） |
| `cm4_carrier.kicad_sch` | E2 CM4 载板（CM4 连接器、双 22P 相机 FPC、TPS22965 负载开关、microSD） |
| `PANO-3U.kicad_sym` | 项目符号库（18 个自定义 IC 符号） |
| `sym-lib-table` | 库映射（已配置，勿删） |
| `预览图/` | 四张原理图预览 PNG（无需 KiCad 即可查看连接关系） |

## 设计约定

- **四块板对应四块独立 PCB**（各 90×90 mm、4 层、Tg150、沉金），经 J1 2×20P 堆栈总线互联；
- 网络连接方式为**网络标签**（label）连通：同名标签即同一网络，KiCad 中可直接生成正确网表；
- J1 引脚定义与《电子系统设计规格书》§0 完全一致，四块板的 J1 网络名逐一对应。

## ⚠️ 投板前必须完成的核对清单

1. **自定义符号引脚号为逻辑编号**（PANO-3U 库中 18 个符号）：Layout 前必须按器件数据手册把每个引脚号映射到正确封装焊盘，重点核对：
   - LT3652（MSOP-12EP 实际封装，图中 DFN16 占位需改）
   - STM32F405RGT6（LQFP-64 实际引脚号，符号内为逻辑序号）
   - RA07H4452M、PE4259、Si4463 模块
2. R/C/L/D/连接器使用 **KiCad 官方库符号**，引脚映射天然正确；
3. 打开工程后运行 **ERC**（检查 → 电气规则），全绿后再画板；
4. 电源完整性：5 V 走线 ≥0.5 mm 宽（或敷铜），VBAT ≥0.8 mm；MIPI 差分对 100 Ω 等长 ±0.5 mm；
5. CM4 双相机：CAM1 为 2-lane，原理图中相机 2 的 D2/D3 已按规格书要求断开（不连接），量产前需在树莓派平台实测 4K30 带宽，不足则按规格书备选方案（CM5 或 USB3 相机）切换。

## 与图纸/BOM 的一致性

本工程网络名、位号与 `PANO-3U_全级BOM清单.xlsx`（E 系列编号）和《电子系统设计规格书》逐条对应；改动任何一处请三处同步。

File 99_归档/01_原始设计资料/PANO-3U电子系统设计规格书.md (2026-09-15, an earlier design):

# PANO-3U 电子系统设计规格书（PCB 原理图设计依据）

**版本 B / 2026-09　|　深度：器件级连接关系 + 全部接插件引脚定义，可直接交 PCB 工程师画原理图与 Layout**

四块板统一规格：90×90 mm、4 层 FR4 Tg150、1 oz 铜、沉金；安装孔 4×Ø3.2（76×76 分布）；板间通过 2×20P 2.54 mm 镀金车针排针（J1，堆栈贯通总线）。层叠建议：Top（信号）/ GND / PWR / Bottom（信号）。

## 0. 堆栈总线 J1（2×20P）引脚定义——四块板统一

| Pin | 信号 | Pin | 信号 |
|---|---|---|---|
| 1 | GND | 2 | GND |
| 3 | VBAT（7.4 V） | 4 | VBAT |
| 5 | +5V | 6 | +5V |
| 7 | +3V3 | 8 | +3V3 |
| 9 | I2C1_SDA | 10 | I2C1_SCL |
| 11 | UART_OBC_TX | 12 | UART_OBC_RX |
| 13 | UART_CM4_TX | 14 | UART_CM4_RX |
| 15 | CAN_H（预留） | 16 | CAN_L（预留） |
| 17 | DEPLOY_EN（热刀使能） | 18 | ANT_STAT（展开遥测） |
| 19 | SAFE_MODE | 20 | WD_KICK |
| 21 | MAG_X_PWM | 22 | MAG_Y_PWM |
| 23 | MAG_Z_PWM | 24 | HEAT_EN |
| 25 | SW_STAT（分离开关状态） | 26 | PAYLOAD_EN |
| 27–40 | GND/预留 | | |

每块板 J1 只引出本板用到的网络，但**排针必须全位数贯通**（堆栈结构件）。

---

## 1. E8 EPS 电源板

### 1.1 功能框
太阳阵 4 面（11.4 V/0.45 A 每面）→ LT3652 ×4（独立 MPPT 充电）→ 汇流（LTC4412 理想二极管）→ 2S 电池组（经 BMS + 分离开关×3 + RBF）→ 母线 VBAT → TPS54331（5 V/3 A）→ TLV70233（3.3 V/2 A）。

### 1.2 器件级连接

**LT3652（U1–U4，每面一路）**
- VIN：太阳阵输入，10 µF 陶瓷 + 100 µF 钽；MPPT 设定：VIN_REG 分压至 11.4 V（R 网络：R1=604 kΩ / R2=60.4 kΩ）
- BAT 输出：8.4 V 浮充（2S Li-ion），充电电流设 0.5 A（R_SENSE=0.2 Ω）
- TIMER 接地（C/10 终止），NTC 接 10 kΩ B=3380 热敏电阻（贴电池）
- 四路输出各经 **LTC4412 + P-MOSFET（Si2343）** 理想二极管汇流至充电母线

**分离开关/RBF 链路**（位于电池正极路径）：BAT+ → BMS P+ → J2.1 → SW1 → SW2 → SW3 → J3 RBF → VBAT
- SW 为三微动开关常闭触点串联，滚轮被 P-POD 压紧时**闭合**（注意：发射态闭合但 RBF 断开；入轨弹开→接通）
- RBF：Ø6.35 插销机械保持常开微动断开，拔除→闭合

**DC/DC**
- TPS54331（U6）：VBAT→5 V/3 A，L=10 µH（饱和电流≥4 A），输出 22 µF×2
- TLV70233（U7）：5 V→3.3 V/2 A，或 TPS54331 第二路
- 各输出支路串 **TPS2553** 电子保险丝：5 V-CM4 限 3 A、3.3 V-OBC 限 1 A、相机限 1.5 A、加热片限 1 A

**遥测**：INA226 ×4（I2C1，地址 0x40/41/44/45）：VBAT 电压电流、5 V 电流、充电电流、电池电压

**接插件**
- J4/J5/J6/J7：JST XH-2P，太阳阵 ±X/±Y 输入（Pin1=+，Pin2=−）
- J2：JST XH-2P 至分离开关链路；J3：RBF 座
- J8：JST XH-2P，5 V→CM4 载板；J9：JST SH-6P 至加热片×2+温控×2

### 1.3 Layout 要点
功率回路（LT3652 SW 节点、电感、采样电阻）最短路径，远离 INA226 采样；太阳阵输入 TVS（SMBJ15A）；板边铺铜接结构地（单点，经 1 MΩ+10 nF）。

---

## 2. E7 OBC 板

### 2.1 器件与连接

**STM32F405RGT6（U1）**
- HSE 8 MHz 晶振 + 32.768 kHz；BOOT0 下拉 10 kΩ；NRST 接 TPS3823-33 看门狗输出
- SWD 调试口：2×5P 1.27 mm（J10），测试点引出
- **I2C1**（PB6/PB7，上拉 2.2 kΩ 至 3V3）：J1.9/10 → INA226×4、QMC5883L（0x0D）、MPU-9250（0x68）
- **UART1**（PA9/PA10）：J1.11/12 → E9 通信板（9600 8N1，AX.25 帧）
- **UART2**（PA2/PA3）：J1.13/14 → CM4 载板（115200 8N1，遥测/指令）
- **TIM1 CH1–CH3**（PA8/PA9 冲突→改用 PE9/PE11/PE13）：J1.21/22/23 → DRV8837 ×3 磁力矩器
- **GPIO**：PA0=HEAT_EN（J1.24），PA1=DEPLOY_EN（J1.17，高电平触发热刀 3 s 脉冲），PA5=ANT_STAT 输入（J1.18），PA6=SW_STAT 输入（J1.25），PA7=PAYLOAD_EN（J1.26），PB0=WD_KICK（J1.20，软件 1 Hz 翻转喂 TPS3823）
- **SPI2**（PB13–15）：W25Q128JV（U2，固件镜像+参数表备份）
- **1-Wire**（PC6，4.7 kΩ 上拉）：DS18B20 ×6 总线
- RTC：DS3231（I2C1 0x68 冲突→移至 I2C2 PB10/PB11），CR1220 备份电池

**电源**：J1 取 3V3，每 VDD 100 nF + 4.7 µF；VDDA 经磁珠+1 µF。

### 2.2 软件接口
- 遥测帧（1 Hz 记录，过境下传）：VBAT、各支路电流、6 路温度、姿态（磁强计/陀螺）、模式字、看门狗计数
- 指令：模式切换、拍摄计划上传、热刀释放（双重确认+延时）、参数表更新
- 安全模式：Vbat<6.6 V 或看门狗复位 → 关载荷/加热优先保电

---

## 3. E9 UHF 通信板

- **DRF4463 模块**（Si4463，433/437 MHz）：SPI 接 J1 扩展（经 OBC 转接或直接挂 SPI2 冲突→用 USART3 模拟/SPI1 PB3–5 + NSS PA15）；TXEN/RXEN 由 OBC GPIO 经 J1.27/28
- **PA**：RF2126 或 RA07H4452M（437 MHz 1 W），供电 5 V 经 TPS2553（限 1.5 A），TX 时使能
- **收发切换**：PE4259 SPDT；**SAW 滤波**：B39162 系列（437 MHz）于天线口
- **天线口**：SMA-KY（J12）→ RG178 → 天线；巴伦 1:1（绕线变压器）置于天线安装座侧
- 时钟：30 MHz TCXO（Si4463 配套，频偏 ≤±2 ppm——多普勒 ±10 kHz 内需）

---

## 4. E2 CM4 载板

- **CM4 插座**：2×100P 高密度座（Hirose DF40C-100DP）
- **相机**：CAM0/CAM1 22P 0.5 mm FPC 座（J20/J21，注意 CM4 上 CAM1 仅 2-lane→IMX477 用 CAM0(4-lane) 接相机 1 高分辨率模式，CAM1 需飞线 I2C 使能第二路——**工程实现要点：CM4 双相机需 device tree 同时使能 CAM0/CAM1，CAM1 为 2-lane，IMX477 4-lane 降 2-lane 带宽足够 4K30 需实测验证；备选方案：换 CM5 或使用 USB3 相机模组**）
- **供电**：5 V/3 A 经 J1.5/6 进入，板载 3.3 V（CM4 内部 PMIC 用 5 V）；TVS SMBJ5.0A
- **eMMC/启动**：CM4 4 GB/32 GB eMMC 版；nRPIBOOT 跳线座（烧录用）
- **接口至 OBC**：UART（GPIO14/15）电平直连 J1.13/14；GPIO17=PAYLOAD_EN 输入（低电平时 CM4 断电——经负载开关 TPS22965 控制 5 V）
- **存储**：microSD 卡座（J22，UHS-I）用于图像数据；eMMC 存系统
- **散热**：CM4 顶面导热垫（1 mm，6 W/m·K）→ 铝散热块 → 4×M3 铜柱 → 端板框架
- **实时性**：双相机同步——用同一 GPIO（GPIO4）输出硬件触发至两相机 FSIN（HQ 相机支持外触发焊接点），同步误差 <1 ms

---

## 5. 传感器与执行器接口

| 器件 | 接口 | 供电 | 备注 |
|---|---|---|---|
| MPU-9250 | I2C1 0x68 | 3V3 | 装于 OBC 板 |
| QMC5883L | I2C1 0x0D | 3V3 | 远离磁力矩器 ≥40 mm |
| DS18B20 ×6 | 1-Wire PC6 | 3V3 | 电池×2/相机×2/板卡×2 |
| DRV8837 ×3 | TIM1 CH1–3 | 5 V | 线圈电流 ≤0.8 A，串联限流电阻实测标定 |
| 加热片 ×2 | HEAT_EN→AOD510 | 5 V | 与 KSD9700 温控串联（硬件双保险） |
| 热刀 ×2 | DEPLOY_EN→IRLML6344 | VBAT | 3 s 脉冲，双刀冗余 |

## 6. 设计规则（Layout 通用）

1. 全部电解电容禁用品，用钽/陶瓷（航天可靠性）；
2. 去耦：每 IC 电源脚 100 nF 贴装距离 <2 mm；
3. 高速（MIPI、SPI>10 MHz）走线阻抗 50 Ω 控，MIPI 差分 100 Ω±10%、等长 ±0.5 mm；
4. 板边 3 mm 禁布（铜柱安装区）；安装孔接地过孔阵列；
5. 晶振包地；SWD/UART 测试点全引出；
6. 三防漆（可选）：装配联试后喷涂，连接器遮蔽。

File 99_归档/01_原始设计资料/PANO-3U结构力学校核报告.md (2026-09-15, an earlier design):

# PANO-3U 结构力学校核报告

**版本 B / 2026-09　|　方法：解析法（梁模型 + Miles 方程 + 螺钉强度），发射前须以 FEA 复核电测数据为准**

## 1. 输入条件

| 项 | 取值 | 来源 |
|---|---|---|
| 总质量 | 2.2 kg（含 25% 裕量） | 质量预算 |
| 包络 | 100×100×340.5 mm | CDS Rev.14 |
| 结构材料 | 6061-T6，E=68.9 GPa，ρ=2700，σy=276 MPa | MMPDS |
| 准静态 | 10 g（三向包络） | 典型搭载要求 |
| 随机振动 | GEVS 鉴定级 14.1 gRMS，PSD 平台 0.16 g²/Hz | GSFC-STD-7000 |
| 一阶频率要求 | ≥100 Hz | 避免与火箭耦合 |

## 2. 一阶频率（梁模型）

4 根 8.5×8.5 导轨并联抗弯，含移轴项（d=45.75 mm）：
I_total = 4×(8.5⁴/12) + 4×72.25×45.75² = **606,635 mm⁴**

- 悬臂模型（保守）：f₁ = (1.875²/2π)·√(EI/wL⁴) = **388 Hz**
- 简支模型（上限）：f₁ = **1090 Hz**
- 实际边界介于两者之间，即便按悬臂也 **3.9 倍于 100 Hz 要求** ✅

## 3. 准静态 10 g

| 校核项 | 载荷/应力 | 许用 | 安全系数 |
|---|---|---|---|
| 导轨轴向压应力 | 0.75 MPa | 276 MPa | 368 |
| 导轨压杆屈曲 | 临界 10,206 N vs 实际 54 N | — | 189 |
| 侧板面内应力（1.5 mm） | ≈12 MPa | 276 MPa | 23 |

## 4. 随机振动（Miles 方程，Q=10，fn=150 Hz 保守取值）

- 输出响应 **19.4 gRMS**，3σ 峰值 **58 g**
- 最不利集中质量：电池组 0.5 kg → 286 N 惯性力

## 5. 紧固件校核（随机振动 3σ 工况）

| 连接 | 单钉载荷 | 应力 | A2-70 许用 | 安全系数 |
|---|---|---|---|---|
| 电池支架 4×M3（剪切） | 71.5 N | 10.1 MPa | 310 MPa | 31 |
| 侧板 F2 沉头 M3×10（拉伸） | 8.6 N | 1.7 MPa | 450 MPa | 258 |
| 镜座 M2×4 | 7.1 N | 3.6 MPa | 450 MPa | 125 |

全部安全系数 **≥30**（含力矩预紧后仍充分）✅

## 6. 结论与遗留项

1. 结构静强度、稳定性、刚度（频率）、紧固件全部满足，裕量充分；
2. 本报告为解析法先行版。**发射服务商审查通常要求 FEA 报告**——建议用交付的 STEP 装配体在 ANSYS/ABAQUS 中做模态+随机振动分析复核（网格 2 mm，导轨接触面绑定，PCB 以质量点等效）；
3. 鉴定级振动试验后复测一阶频率（衰减 <5% 判合格）并全数检查螺钉见证标记。

---

## v4 补遗（设计评审后仿真复算）

1. **质量修正**：按几何体积重建的干质量为 2.36 kg（早期 BOM 估算 1.73 kg 低估了导轨/侧板实重），发射质量取 2.83 kg（+20% 裕量）。本报告各项载荷按质量线性放大 ≈10%，所有安全系数仍 ≥25，结论不变。
2. **基频修正**：计入侧板弯曲刚度后全截面 I=1.354×10⁶ mm⁴（原仅计导轨 0.607×10⁶），梁有限元（24 单元+集中质量）复算 **f1=611 Hz**（悬臂），比原解析值 388 Hz 更高，结论更宽裕。
3. **随机振动**：GEVS 包络下 Miles 响应 39.2 gRMS（3σ=118 g）；相机支架 M2×4 螺钉剪切 SF=52，电池支架 M3×4 SF=36，导轨压应力 SF=76，屈曲 SF≫100。
4. 数据文件见 `仿真数据/结构_强度裕度表.csv`。

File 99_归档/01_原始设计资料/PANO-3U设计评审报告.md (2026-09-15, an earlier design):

# PANO-3U 设计评审报告（错误与风险清单）

**版本 v1 / 2026-09　|　对象：版本 B 全套交付物（说明书、图纸 v3、DXF、STEP、KiCad、软件包、BOM）**
**结论摘要：发现 3 项阻断级错误、3 项高风险错误（全部已在版本 C / 图纸 v4 中关闭），7 项中低风险（2 项已修、5 项给出处置），6 项必须在投制/发射前由第三方或试验完成的开放项。**

---

## 一、阻断级错误（已修复，不修复则卫星不合规或无法总装）

### E1　相机装于 ±Z 端面——违反 CDS 且物理上无法成立 【已关闭】
- **问题**：CDS Rev.14 规定卫星端面（±Z）不允许任何凸起，且 P-POD 内多星叠放时端面直接接触。原设计镜头外伸端板 4 mm，超限。更根本的是：镜头若缩回端板内侧，195° 视场的边缘光线（97.5°）会被板厚遮挡——镜头节点埋入 2 mm 时 Ø22 孔只能通过 ±80°，FOV 永远达不到 195°。该方案在几何上就不成立。
- **处置**：相机改至 **±X 侧面**对置安装（CDS 允许侧面凸起 ≤6.5 mm，设计外伸 6.0 mm），新增 MEC-111 相机支架、MEC-103A 相机面板（Ø26 窗 + 4×M2），±X 面太阳阵 20 片减为 16 片（整星 72 片、18.4 W BOL、日发电 74 Wh，裕量 2.5× 仍充足）。
- **已修订文件**：说明书 §1.2/§2/§3.1/§5、图纸 v4 的 S1/S2/S5/S8、新增 S18、DXF×3、STEP 装配体与预览图、BOM。

### E2　分离开关逻辑接反——卫星会在火箭舱内带电 【已关闭】
- **问题**：原文档"装入 P-POD 压紧→触点闭合"。RBF 销在发射前必须拔除，此后若开关闭合，卫星在舱内即上电，**直接违反 CDS 禁上电条款，会被发射商拒载**。
- **处置**：3 只开关统一改为 SPDT **常闭（NC）接法：压紧＝断开（舱内断电，与 RBF 无关），弹出＝闭合（分离后自动上电）**；RBF 保留为地面操作期的独立第二重断电（插入＝断）。
- **已修订文件**：说明书 §4.3（含勘误说明）、BOM E21/E22 备注。

### E3　90×90 mm 电路板/隔板与导轨几何干涉 【已关闭】
- **问题**：内部净宽仅 83 mm（100 − 2×8.5），90 mm 见方的板四角（|x|>41.5 且 |y|>41.5 区域）与导轨实体冲突，按原图根本无法装入。
- **处置**：所有 PCB 与 MEC-105 隔板**四角切 45° 缺口**（去除 |x|>41 且 |y|>41 角区，净间隙 ≥0.5 mm；安装孔 76×76 分布不受影响）。
- **已修订文件**：说明书 §4.1、MEC-105 DXF、STEP 装配体（所有板卡带缺口重建）。

---

## 二、高风险错误（已修复）

### E4　CM4 支路负载开关选型超限 【已关闭】
TPS2553 限流上限 1.7 A，而 CM4 支路设计 3 A。**已改 TPS2557**（0.5–5 A，同 SOT-23-6 封装），KiCad EPS 页 U20 与 BOM E8 已同步；U21–U23（≤1.5 A 支路）保留 TPS2553。

### E5　相机 2 的 4K30 视频在带宽上不可行 【已关闭，指标调整】
CM4 的 CAM1 仅 2-lane CSI（约 2 Gbps），4056×3040@30 RAW10 需 3.7 Gbps。**指标调整为：相机 1（CAM0，4-lane）4K30，相机 2 为 2.8K30 或全分辨率 13 fps**；拍照双机均全分辨率不受影响。说明书 §1.1/§3.2 已改。若必须双 4K30，需升级 CM5（CAM1 变 4-lane）——成本 +¥300 级别，列为可选项。

### E6　M12 鱼眼镜头与 HQ 相机接口不匹配 【已关闭】
HQ 相机为 CS 接口。已增加 **M12→CS 转接环（E33，×2）**，并要求装配后以实距靶复测后截距再锁焦。BOM、图纸 S8、说明书 §3.1 已同步。

---

## 三、中低风险项

| 编号 | 问题 | 等级 | 处置 |
|---|---|---|---|
| R1 | 地面站 receiver.py 把 KISS 帧当含 FCS 原始帧解析，`frame[16:-2]` 会误删 2 字节载荷 | 中（功能 bug） | **已修**：KISS 模式取 `frame[16:]`，回归测试 6/6 通过 |
| R2 | main.py 状态包"运行时长"字段误发纪元秒 | 低 | **已修**：改用单调时钟计时 |
| R3 | MPU-9250 已停产（EOL） | 中 | BOM 标注替代型号 BMI270+IST8310，二选一即可 |
| R4 | 展开后的 UHF 天线振子进入全景边缘视场 | 低 | 不遮挡主体；地面拼接掩膜已能处理，接受 |
| R5 | SAFE 模式原设计关闭加热回路，夜间电池可能低温 | 中 | **已修**：说明书 §5 改为 SAFE 下电池加热保持使能 |
| R6 | CDS 要求"分离后延时禁射频"的时长不同发射商取 30/45 min | 低 | 固件中已是参数（`DEPLOY_DELAY_S`），按发射商要求改数值即可 |
| R7 | 相机改侧面后，±X 面太阳阵减为 16 片 | 低 | 能源复核 72 片/74 Wh/裕量 2.5×，成立（见 §五验证） |

## 四、开放项（非错误，但必须在投制/发射前完成）

1. **FEA 有限元复核**：现结构校核为解析法（f1=388 Hz、屈服 SF≥189 等），发射商普遍要求 ANSYS/NASTRAN 报告——这是流程要求，不是设计缺陷。
2. **镜头实物验证**：f=1.4 mm 标品的真实 FOV、畸变曲线与等距投影偏差须采购样片实测；>3% 偏差时用 5 阶多项式建模（标定管线已支持）。
3. **辐照评估**：全部为 COTS 器件，未做 TID/SEE 分析。1 年以内 LEO 任务通常可接受，建议关键页（OBC 固件、存储）依赖已有的 W25Q128 冗余 + 看门狗复位链，必要时补 30 krad 级 TID 摸底。
4. **热真空试验验证**：单节点热分析为粗估（镜头侧日照区局部可超 +45 °C），以 TVAC 四循环实测为准。
5. **EMC/无线电台执照**：437 MHz 发射需办理业余或业务频率许可；整星 EMC 自兼容测试（PA 发射时 IMU/磁强计读数跳变）未做。
6. **软件在环硬件联调**：`payload_read_chunk()` 目前仍是占位实现（需按 OBC↔CM4 实际 UART 对接联调）；HDLC 位填充在固件中为简化实现，联调时按 Si4463 数据手册补齐。两者均已在代码注释和协议文档中显式标注。

## 五、关键复核数据

| 项目 | 结果 | 判定 |
|---|---|---|
| 链路预算 437 MHz / 500 km / 1 W / 9.6 kbps | 接收 −95 dBm vs 灵敏度 −120 dBm，裕量 **25 dB** | ✓ |
| 能源（v4 后 72 片） | 日发电 74 Wh vs 日耗 30 Wh，**2.5×** | ✓ |
| 相机视场几何（侧装） | 外伸 6.0 ≤ 6.5 mm；边缘光线掠过板面，掩膜可处理 | ✓ |
| 端面凸起 | v4 后端面无任何凸起 | ✓ CDS |
| PCB↔导轨间隙 | 缺口后 ≥0.5 mm | ✓ |
| 载荷软件回归 | pytest **6/6 通过**（修复后复测） | ✓ |
| 质量预算 | 修订净增 ≈25 g，2.19 kg ≤ 2.2 kg 目标 | ✓ |
| 成本 | 硬件 ≈¥20,699，整星 ≈¥4.57 万（不含发射） | ✓ |

## 六、版本 C（v4）修订文件清单

说明书版本 C、图纸 v4（18 页：替换 S1/S2/S5/S8、新增 S18）、DXF 13 个（MEC-103→103A/103B、105 加缺口、新增 MEC-111）、STEP 装配体与 MEC-111 单件 + 预览图 v4、KiCad（U20→TPS2557、README 注记）、BOM（4 处改 + E33 新增）、软件包（receiver.py、main.py 两处修复）。

**评审结论**：阻断级与高风险问题已全部闭环；在完成第四节 6 项开放项（其中 FEA、热真空、镜头实测为硬性门槛）之前，可投入结构件与 PCB 打样，**不建议直接投产飞行件**。

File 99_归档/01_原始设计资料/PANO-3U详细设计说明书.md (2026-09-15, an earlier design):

# PANO-3U 双鱼眼全景立方星 详细设计说明书（工程实施版）

**版本 B / 2026-09　|　深度：逐零件、逐螺钉、逐孔位，可直接投制**

配套文件：
- 三维模型：`STEP模型/`（10 个零件 STEP + 1 个整星装配体 STEP，可导入 SolidWorks/UG/FreeCAD）
- 软件包：`软件包/`（载荷软件/OBC固件/地面站/通信协议）
- 结构校核：`PANO-3U结构力学校核报告.md/.docx`
- 电路设计：`PANO-3U电子系统设计规格书.md/.docx`
- 图纸册：`图纸/3U全景立方星全套图纸_v4评审修订版.pdf`（18 张 A3）
- 加工文件：`图纸/DXF加工文件/`（13 个 DXF，可直接发 CNC/激光切割/PCB 厂）
- 物料清单：`PANO-3U_全级BOM清单.xlsx`（机加件/紧固件/电气电子/成本汇总 4 表）

---

## 第一部分　总体

### 1.1 任务与指标

3U 立方星（100.0×100.0×340.5 mm，Cal Poly CDS Rev.14），双鱼眼侧面对置全景成像，500 km SSO，全景输出 5760×2880；视频 4K30（相机1）+ 2.8K30（相机2），拍照双机全分辨率 4056×3040。**数传口径（v4 仿真定值）：UHF 9.6 kbps 日吞吐仅 0.8 MB，默认升速至 57.6 kbps（链路裕量仍 ≥10.7 dB，日吞吐 4.6 MB，下遥测+快视图+选定压缩照片）；4K 视频存 512 GB 卡（可存 1365 min）仅下抽帧，如需视频级下传需选装 S 频段发射机**，总质量 2.83 kg（几何重建干质量 2.36 kg + 20% 增长裕量；v4 评审发现早期按 BOM 估算的 1.73 kg 低估了导轨/侧板实重约 27%，已按解析体积修正；CDS 3U 上限 4.8 kg，裕量充足）。质心 z=147 mm（几何中心下方，重力梯度有利），硬件成本 ≈2.1 万元。

### 1.2 布局（沿 Z 轴，0 为 −Z 端面）

| Z 区间 (mm) | 内容 |
|---|---|
| 0–30 | −Z 端板（分离开关/RBF 界面） + 堆栈底座 |
| 30–123 | 电子堆栈：UHF 通信板 → EPS 板 → 隔板 → OBC 板 → CM4 载板（PC/104 式 M3 铜柱互联） |
| 123–227 | 电池舱：2×MEC-106 支架抱箍 4×18650（2S2P），两侧对称（±Y 侧），加热片+测温 |
| 150–200（±X 侧面） | **相机模组 1/2 对置于 ±X 侧板**，镜头朝 ±X 外伸 ≤6.0 mm（CDS 侧面凸起限值 6.5 mm 内） |
| 227–340.5 | +Z 舱段（走线/余量）+ +Z 端板 |

---

## 第二部分　机械设计（逐零件）

### 2.1 机加件清单（10 种，详见 BOM 表"机加件"）

| 图号 | 名称 | 材料/厚度 | 数量 | 单件质量 | 关键要求 |
|---|---|---|---|---|---|
| MEC-101 | +Z 端板 | 6061-T6 t=2.0 | 1 | 46 g | 相机基准面，沉孔与通孔同轴度≤0.05 |
| MEC-102 | −Z 端板 | 6061-T6 t=2.0 | 1 | 48 g | 分离开关孔位公差 ±0.05（CDS 界面） |
| MEC-103A | 侧板-相机面（±X） | 6061-T6 t=1.5 | 2 | 92 g | Ø26 相机窗 + 4×M2 攻丝；沉孔朝外 |
| MEC-103B | 侧板-普通面（±Y） | 6061-T6 t=1.5 | 2 | 96 g | 贴片区平面度≤0.2，沉孔朝外 |
| MEC-104 | 导轨 | 6061-T6 | 4 | 52 g | 直线度≤0.05/340，接触面 Ra≤1.6 |
| MEC-105 | 中部隔板 | 6061-T6 t=1.5 | 3 | 28 g | 导电氧化，减重孔 R4 |
| MEC-106 | 电池支架（U 型） | 6061-T6 t=1.5 | 2 | 35 g | 折弯件，抱箍 2 节 18650 |
| MEC-107 | 相机镜座 | 6061-T6 车件 | 2 | 18 g | M14×0.5 与镜头配作，止口 Ø22H7 |
| MEC-111 | 相机支架（L 型） | 6061-T6 t=2.0 | 2 | 16 g | 镜座与传感器板一体定位，装于侧板内侧 |
| MEC-108 | 分离开关支架 | 6061-T6 t=1.2 折弯 | 1 | 12 g | 3 只微动开关对准 −Z 端板孔 |
| MEC-109 | 天线安装座 | 6061-T6 | 2 | 10 g | 含热刀绕线柱 |
| MEC-110 | 压线卡 | 6061-T6 | 10 | 1.5 g | 线束固定，间距 ≤80 mm |

### 2.2 端板孔位坐标表（基准：板中心，单位 mm，±0.05）

**通用孔（±Z 端板相同）**

| 编号 | X | Y | 规格 |
|---|---|---|---|
| H1–H4 | ±45.75 | ±45.75 | Ø3.4 通孔（导轨端面螺钉 F1 穿入） |
| H5–H12 | ±25 | ±44 及 ±44 | ±25 | Ø3.2 通孔 ×8（辅助/扎线/内部支架） |
| H13–H16 | ±38 | ±38 | Ø3.2 通孔 ×4（堆栈铜柱 F6） |
| C1 | 0 | 0 | 60×30 通孔（走线减重，R4 圆角） |
| ~~L1 / M1–M4~~ | — | — | **v4 已取消**：相机改至 ±X 侧面，端板恢复为完整板面（仅保留 C1 走线孔），刚度提升 |

**−Z 端板追加**

| 编号 | X | Y | 规格 |
|---|---|---|---|
| S1 | +30.00 | −45.75 | Ø4.4 通孔（分离开关 1） |
| S2 | −30.00 | −45.75 | Ø4.4 通孔（分离开关 2） |
| S3 | +45.75 | 0.00 | Ø4.4 通孔（分离开关 3） |
| R1 | −45.75 | +30.00 | Ø6.3 通孔（RBF 销） |

### 2.3 侧板孔位（基准 A=左端面，B=下边缘，单位 mm）

- 端部辅助孔 H1–H4：(12, 16.5)、(12, 66.5)、(328.5, 16.5)、(328.5, 66.5)，Ø3.2；
- 导轨固定孔 K1–K10：X = 30/90/170/250/310 × Y = 6/77，Ø3.2 通孔 + **外表面 Ø6×90° 沉孔**（F2 沉头螺钉与板面齐平，避免侧向凸起超限）；
- 过线孔 P1（仅 MEC-103B）：(170, 41.5)，Ø6（太阳阵引线入内，加护套）；
- **MEC-103A 相机窗**：(170, 41.5)，Ø26 通孔 + 内侧孔口 0.3×45° 去毛刺；周圈 4×M2 攻丝深 4，位于 (170±12, 41.5±12)，用于 MEC-111 支架（F14）；
- 外表面贴片区 3 段 92×71（起始于 X=14/121/228），贴片区**不氧化**（裸铝导电氧化）；MEC-103A 中段贴片让位于相机窗，太阳阵 16 片布局（见图纸 S10B）。

### 2.4 导轨（关键件，×4）

- 截面 8.5×8.5（+0/−0.05），全长 340.5±0.1，两端倒角 C0.5（P-POD 导入）；
- 端面 M3 攻丝深 10（距端面 6，两端各 1）→ F1 螺钉；
- 两侧面 M3 攻丝深 6，位于 X=30/90/170/250/310（与侧板 K1–K10 对应）；
- 接触面硬质阳极氧化 ≥25 µm、Ra≤1.6，**氧化后禁止再加工**；全长直线度≤0.05，扭曲≤0.05，端面垂直度≤0.05。

### 2.5 紧固件总表（共 ≈150 颗，详见 BOM 表"紧固件与胶接"）

| 编号 | 规格 | 数量 | 力矩 | 防松 | 位置 |
|---|---|---|---|---|---|
| F1 | M3×8 内六角圆柱头 A2-70 | 8 | 1.0 N·m | Loctite 243 | 端板↔导轨端面（4 角×2 端） |
| F2 | M3×6 内六角沉头 A2-70 | 40 | 1.0 N·m | Loctite 243 | 侧板↔导轨侧面（4 面×2 轨×5 点） |
| F3 | M3×6 盘头 + 弹垫 | 20 | 1.0 N·m | 弹垫 | 堆栈板/隔板/开关支架 |
| F4 | M3×15 双通铜柱 | 8 | 手紧+1/4 圈 | 243 | CM4 载板↔OBC 层距 |
| F5 | M3×12 双通铜柱 | 8 | 手紧+1/4 圈 | 243 | OBC↔EPS、EPS↔通信板层距 |
| F6 | M3×10 双通铜柱 | 4 | 手紧+1/4 圈 | 243 | 堆栈底座 |
| F7 | M2.5×8 盘头 + 弹垫 | 8 | 0.5 N·m | 弹垫 | 相机传感器板（4/机） |
| F8 | M2×6 沉头 | 8 | 0.3 N·m | 243 | 镜座↔MEC-111 支架（4/座） |
| F14 | M2×8 盘头 + 弹垫 | 8 | 0.3 N·m | 243 | MEC-111 支架↔MEC-103A 侧板（4/机） |
| F9 | M3×8 盘头 + 弹垫 | 8 | 1.0 N·m | 弹垫+F13 螺母 | 电池支架↔隔板 |
| F10 | M2×5 沉头 | 6 | 0.3 N·m | 243 | 天线座/开关支架 |
| F11–F13 | M3 平垫 ×40 / 弹垫 ×28 / 尼龙锁紧螺母 ×8 | — | — | — | 配用 |

**装配铁律**：所有螺纹连接涂 Loctite 243（自锁螺母除外）；力矩螺丝刀使用前校准；拧紧后做漆笔见证标记；对角顺序分两次拧紧（50%→100%）。

---

## 第三部分　载荷（双鱼眼全景相机）

### 3.1 光学设计定值

- 传感器：Sony IMX477，4056×3040，像元 1.55 µm，感光面 6.29×4.71 mm；
- 镜头：M12×0.5，**f=1.4 mm**，F2.4，FOV≥195°（对角），等距投影 r=f·θ——由像圆半径 2.356 mm 与 θ_max=97.5° 反算 f=1.38 mm，取 1.4 mm 标品，采购时**向供应商索取畸变曲线表**确认等距投影（偏差 >3% 则在标定中以 5 阶多项式建模）；
- 角分辨率 15.6 px/°；拼接输出 5760×2880 equirectangular；双机对置重叠区 15°（≥8° 匹配下限的 1.9 倍）；
- 滤光：650 nm IR-cut（Ø8×0.55）贴于镜座后端面；
- 装配基准链：镜头 → 镜座 MEC-107（止口 Ø22H7 配 MEC-111 沉孔）→ 支架 MEC-111 → MEC-103A 侧板（窗孔同轴度≤0.05）——单链三级，误差可控；
- 安装：双机对置于 ±X 侧板中心（Z=170），光轴沿 ±X；**镜头前端面外伸 ≤6.0 mm，满足 CDS 侧面凸起 ≤6.5 mm**；端面（±Z）无任何凸起；
- 镜头接口：HQ 相机为 CS 口，加 M12→CS 转接环（E33）后拧入 M12 鱼眼；转接后按实距靶复测后截距并锁焦；
- 调焦：实距标定靶 1.5 m，中心 MTF 最优点锁焦，Loctite 401 三点点胶，静置 24 h 后复测。

### 3.2 标定与拼接管线

1. 出厂：旋转棋盘格法，每相机 ≥30 姿态，解内参（f、cx、cy、k1–k4）与双机外参（R,t），写入星上参数表（JSON，OBC 与 CM4 双备份）；
2. 星上：双机硬同步触发（<1 ms）→ RAW 采集 → ISP → H.265 存 microSD（相机1：4K30，CAM0 4-lane；相机2：2.8K30 或全分辨率 13 fps，CAM1 2-lane 带宽约 2 Gbps 上限）；抽 1/16 分辨率快视图；
3. 地面：等距投影半球展开 → 重叠区 ORB 特征匹配 + 光流亚像素对齐 → 多频段融合 → 5760×2880 输出；
4. 在轨修正：利用重叠区恒星匹配每 30 天校正外参漂移。

---

## 第四部分　电气电子（逐板卡）

### 4.1 板卡与堆栈

堆栈自下而上（−Z→+Z）：**E9 UHF 通信板 → F5 铜柱 → E8 EPS 板 → MEC-105 隔板 → F5 铜柱 → E7 OBC 板 → F4 铜柱 → E2 CM4 载板**；板间 2×20P 镀金车针排针（E23）贯通总线；所有 PCB 90×90 mm，**四角切 45° 缺口（去除 |x|>41 且 |y|>41 角区，避让 8.5 mm 导轨，净间隙≥0.5 mm）**，4×Ø3.2 安装孔（76×76 分布），4 层 FR4 Tg150 1 oz 沉金；MEC-105 隔板同规缺口。

| 板卡 | 核心器件 | 关键设计 |
|---|---|---|
| E7 OBC | STM32F405RGT6 + TPS3823 看门狗 + DS3231 RTC + W25Q128 | 30 s 看门狗；遥测记录；磁控算法 |
| E8 EPS | LT3652×4（每面独立 MPPT 充电通道） + INA226×4 + LTC4412 + TPS2557（CM4 支路 3 A）/TPS2553×3（其余支路） | 母线 5 V/3 A、3.3 V/2 A；支路电子保险丝 |
| E9 通信 | DRF4463（Si4463 成品模块）+ 1 W PA + SAW | 437 MHz，9.6 kbps GFSK，AX.25 |
| E2 CM4 载板 | CM4 插座 + 双 22P CSI + 5 V 输入 + UART/I2C 转接 | CM4 导热垫→铜柱→框架散热 |

### 4.2 线束表（W1–W14，详见图纸 ELE-402）

电源 22AWG、信号 28AWG（均 PTFE/M22759 级）；RF 用 RG178+SMA；相机用 FPC 22P/0.5 异面排线（200/300 mm 贴铜箔屏蔽）；连接器全部带锁（JST XH/SH）。**布线规则**：电源/信号/RF 分束，间距 ≥10 mm，每 80 mm 一只压线卡 MEC-110，连接器插好后点 GD414 硅橡胶应力释放。

### 4.3 分离与 RBF 安全回路

**BAT+ → BMS → SW1 → SW2 → SW3 → RBF → EPS 主输入**（全串联，任一断开即全星断电）。3 只 SPDT 滚轮压杆式微动开关装于 MEC-108 支架，滚轮对准 −Z 端板 Ø4.4 孔，**一律接常闭（NC）触点：装入 P-POD 后滚轮被导轨压入 → 触点断开 → 全星断电（此时 RBF 已拔除也满足 CDS 禁上电要求）；入轨弹射分离后滚轮弹开 → 触点闭合 → 自动上电启动**。RBF 销在地面操作期间提供独立第二重断电保障（发射前拔除）。**（v4 修正：v3 及之前版本“压入→闭合”的描述逻辑相反，在舱内 RBF 拔除后将导致星上带电，违反 CDS Rev.14 §3.3.4，已更正为 NC 接法。）**

---

## 第五部分　电源 / 热 / 姿态（计算定值）

- 太阳阵：±Y 面 20 片 + ±X 面 16 片（让位相机窗）= 72 片 Maxeon Gen3 切割片（22.6×34 mm，0.256 W/片 BOL），±Y 面 20S1P（Vmp=11.4 V）、±X 面 16S1P（Vmp=9.1 V，均在 LT3652 输入范围内）→ 整星 18.4 W BOL，OAP 3.4 W，日发电 ≈74 Wh vs 日耗电 ≈30 Wh（裕量 2.5×）；MPPT 采用 LT3652×4（每面独立通道）；SS34 旁路二极管每 8 片 1 只；3M 966 贴片；
- 电池：NCR18650B×4 2S2P，49 Wh，日食放电深度 7%；加热片 2 W（KSD9700 5°C 闭合/8°C 断开）；
- 功率：待机 0.78 W / 拍摄 9.45 W / 数传 3.75 W；日能耗 ≈30 Wh « 日发电 ≈130 Wh；
- 热（v4 六节点瞬态仿真定值）：热工况全星均衡 15~20°C，无过热风险；**冷工况（最大日食季+SAFE）裸装电池会降至 −21°C，低于 0°C 充电禁限** → 设计修订：电池包加 MLI 多层隔热 + 加热功率 2 W→3 W（占空 79%），且 LT3652 NTC 引脚配置 0°C 充电禁止；修订后冷工况电池 −12~+8°C，日照段恢复充电；相机镜头侧向日照直晒局部可超 +45°C，列入热真空试验验证项；
- ADCS：B-dot 消旋（≤2°/s）+ 磁强计/太阳矢量粗定姿 ±5°；磁力矩器 Ø0.35 漆包线 500 匝×2 + PCB 平面线圈×1，DRV8837 驱动；**全景任务无需反作用轮**。

---

## 第六部分　装配工艺与检验

装配 12 步（A1–A12，详见图纸 ASM-002 工艺表），要点：ESD 台+腕带；A6 相机调焦点胶后静置 24 h；A8 端板螺钉对角分次终拧 1.0 N·m；A10 贴片后测母线-结构绝缘 ≥10 MΩ；A12 称重 ≤2.9 kg、质心偏差 <3 mm（z 向按 147±10 mm 验收）。

**检验项**：导轨直线度 CMM 抽检；端面孔位投影仪全检；振动（GEVS 14.1 gRMS）后首阶频率复测（衰减 <5%）+ 全螺钉见证标记复查；热真空 −20~+50°C 四循环，冷热浸点各完成一次双机拍摄。

---

## 第七部分　成本（详见 Excel）

硬件合计 **≈¥20,699**（机加件 5,790 + 紧固件胶接 263 + 电气电子 11,946 + 镜头备选 200 + 结构备件 2,500）；加测试 2 万与地面站 5 千，整星 **≈¥4.57 万（不含发射）**。

*版本 C（v4 设计评审修订版）：相机改 ±X 侧面安装（CDS 端面凸起合规）、分离开关改 NC 接法、PCB/隔板四角切缺口避让导轨、CM4 支路换 TPS2557、太阳阵 72 片；全部尺寸/孔位/紧固件与 DXF、图纸、BOM 三对照一致；投制前请以 DXF 为准复核一遍孔位坐标表。*

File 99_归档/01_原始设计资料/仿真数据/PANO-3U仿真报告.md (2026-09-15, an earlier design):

# PANO-3U 全套仿真数据报告

**版本 v1 / 2026-09　|　对应设计：版本 C（图纸 v4）**
**方法说明**：全部仿真为 Python 数值计算（轨道力学/有限元/集总热网络/姿态动力学），输入参数取自版本 C 设计文件；CSV 原始数据与本报告同目录。本报告不替代发射商要求的 ANSYS/NASTRAN 正式 FEA 与热真空试验（见设计评审报告开放项）。

---

## S0　质量特性（几何重建法）

按零件解析体积 × 6061-T6 密度 + 分系统实重逐项建表（`质量特性_分部件表.csv`，25 项）：

| 指标 | 数值 | 备注 |
|---|---|---|
| 干质量 | **2359 g** | v4 评审修正项：早期 BOM 估算 1730 g 低估导轨/侧板实重 ~27% |
| 发射质量（+20% 裕量） | **2.83 kg** | CDS 3U 上限 4.8 kg，裕量 41% |
| 质心 | (0.0, −0.2, 146.7) mm | z 向低于几何中心 23.6 mm，重力梯度稳定构型 |
| 惯量 | Ixx=0.0168 / Iyy=0.0173 / Izz=0.00271 kg·m² | 含零件自身惯量+平行轴 |

## S1　轨道仿真（500 km SSO，i=97.40°，T=94.5 min）

- 每天 15.2 轨；**最坏日食（β=0）35.7 min/轨（37.8%）**，β≥65° 时日食降至 14.5 min（`轨道_日食vs太阳角.csv`，圆柱阴影数值积分）；
- 北京站（40°N,116°E，仰角门限 10°）7 天过顶 **20 次（2.9 次/天）**，平均 6.2 min、最大 7.3 min，最大仰角均值 39°（`轨道_北京站过顶预报7天.csv`）。

## S2　能源仿真（最坏工况 β=0、EOL 衰减 0.90、MPPT 效率 0.95）

- 单轨平均发电 3.41 W，**日发电 81.9 Wh vs 日耗 30 Wh，裕量 2.73×**（β 扫描 0°~60° 均 ≥2.7×）；
- 7 天时域仿真（每 30 s 步长，含 4 次/天拍摄 + 过顶数传占空）：**电池 SOC 全程 80%~100%，最低 DoD 仅 20%**（允许 80%）→ 能源闭环成立，日食季无风险（`能源_SOC时域7天.csv`、曲线 PNG）。

## S3　热仿真（六节点集总网络，5 s 步长，48 h）

| 工况 | 内部核心 | 面板 | 电池 | 结论 |
|---|---|---|---|---|
| 热工况（全日照+载荷 2 W） | 15~20°C | 15~19°C | 15~20°C | 无过热风险 ✓ |
| 冷工况（最大日食+SAFE 0.78 W，**原设计裸装+2 W**） | −24~3°C | −26~3°C | **−21~6°C** | ✗ 低于 0°C 充电禁限 |
| 冷工况（**修订：电池 MLI+3 W 加热**） | −20~8°C | −22~7°C | **−12~+8°C** | △ 加热占空 79%，日照段恢复充电 |

**设计修订（已回写说明书 §5）**：电池包外覆 MLI、加热功率 2 W→3 W、LT3652 NTC 引脚配置 0°C 充电禁止。残余风险：极端冷工况电池短时低于 0°C（不充电、可放电至 −20°C），以热真空试验实测收口（`热仿真_节点温度.csv/.png`）。

## S4　结构仿真（一维梁有限元，24 单元 + 9 处集中质量，悬臂边界）

- **基频 f1 = 611 Hz**（计入侧板刚度的全截面 I=1.354×10⁶ mm⁴；远高于 100 Hz 门槛；原解析法 388 Hz 偏保守）；
- 随机振动 GEVS 包络：Miles 响应 39.2 gRMS，3σ=118 g；准静态 10 g 轴向；
- **裕度表（`结构_强度裕度表.csv`）**：导轨压应力 SF=76、屈曲 SF≫100、F2 侧板螺钉剪切 SF=28、电池支架 M3 SF=36、相机支架 M2(F14) SF=52 —— 全部满足。

## S5　ADCS 消旋仿真（四元数姿态动力学 + 倾斜 11.5° 偶极磁场，dt=0.5 s）

- B-dot 控制（m=−K·dB/dt，K=8×10⁵，磁偶极限幅 0.2 A·m²）：初始 10°/s/轴（|ω|=17.3°/s）→ **2.3 h 降至 ≤2°/s**，24 h 后 0.13°/s；
- 对全景任务（要求 ≤2°/s）成立，无需反作用轮的结论经动力学验证（`ADCS_Bdot消旋.csv/.png`）。

## S6　通信链路仿真（437 MHz，1 W，地面 12 dBi 八木）

- 典型过顶（60° 最大仰角）：距离 500~909 km，**链路裕量 18.7~23.9 dB @9.6 kbps**；
- **整星级发现——数传瓶颈**：9.6 kbps 日吞吐仅 **0.76 MB/天**，一张压缩全景照片（~12 MB）需 15 天。仿真核验升速方案：

| 速率 | 灵敏度 | 最低裕量 | 日吞吐 | 判定 |
|---|---|---|---|---|
| 9.6 kbps | −120 dBm | 18.7 dB | 0.8 MB | 遥测够用 |
| **57.6 kbps** | −112 dBm | **10.7 dB** | **4.6 MB** | **✓ 推荐默认（35 张快视图/天 或 1 张全图/2.5 天）** |
| 115.2 kbps | −109 dBm | 7.7 dB | 9.2 MB | 可选 |

- **4K 视频（375 MB/min）物理上无法经 UHF 下传**：存 512 GB 卡（可存 1365 min），仅下抽帧/快视图；如需视频级数据下传，选装 S 频段发射机（1 Mbps → 85 MB/天，约 +¥2500，列为升级项）。说明书 §1.1 已按此口径修订。

## S7　光学仿真

- 等距投影角分辨率 **15.8 px/°（全视场恒定）**，equirectangular 输出 5760×2880 = 16.0 px/° ✓ 匹配；
- 拼接重叠环带 82.5°~97.5°，占全球面 13%（≥8° 匹配下限的 1.9 倍）✓；
- 对地观测 GSD：星下点 0.55 km/px，60° 离轴 2.21 km/px（广角对地为辅助功能，非精细对地遥感）。

---

## 汇总判定

| 仿真项 | 结论 |
|---|---|
| 质量/包络 | ✓ 2.83 kg / CDS 合规（v4 修正） |
| 轨道/过顶 | ✓ 2.9 次/天过顶支撑运维 |
| 能源 | ✓ 最坏工况裕量 2.73×，SOC≥80% |
| 热 | △ 修订后满足（MLI+3W+NTC，TVAC 收口） |
| 结构 | ✓ f1=611 Hz，全部 SF≥28 |
| ADCS | ✓ 2.3 h 消旋达标 |
| 链路 | △ 升速 57.6 kbps 后满足运营；视频下传需 S 频段升级项 |
| 光学 | ✓ 指标闭环 |

**仿真口径免责声明**：轨道为二体+J2 模型；磁场为倾斜偶极子；热为 6 节点集总；结构为一维梁 FE。以上用于方案级验证与设计定值，正样阶段须以高保真工具（STK/IGRF/ESATAN/ANSYS）复核。

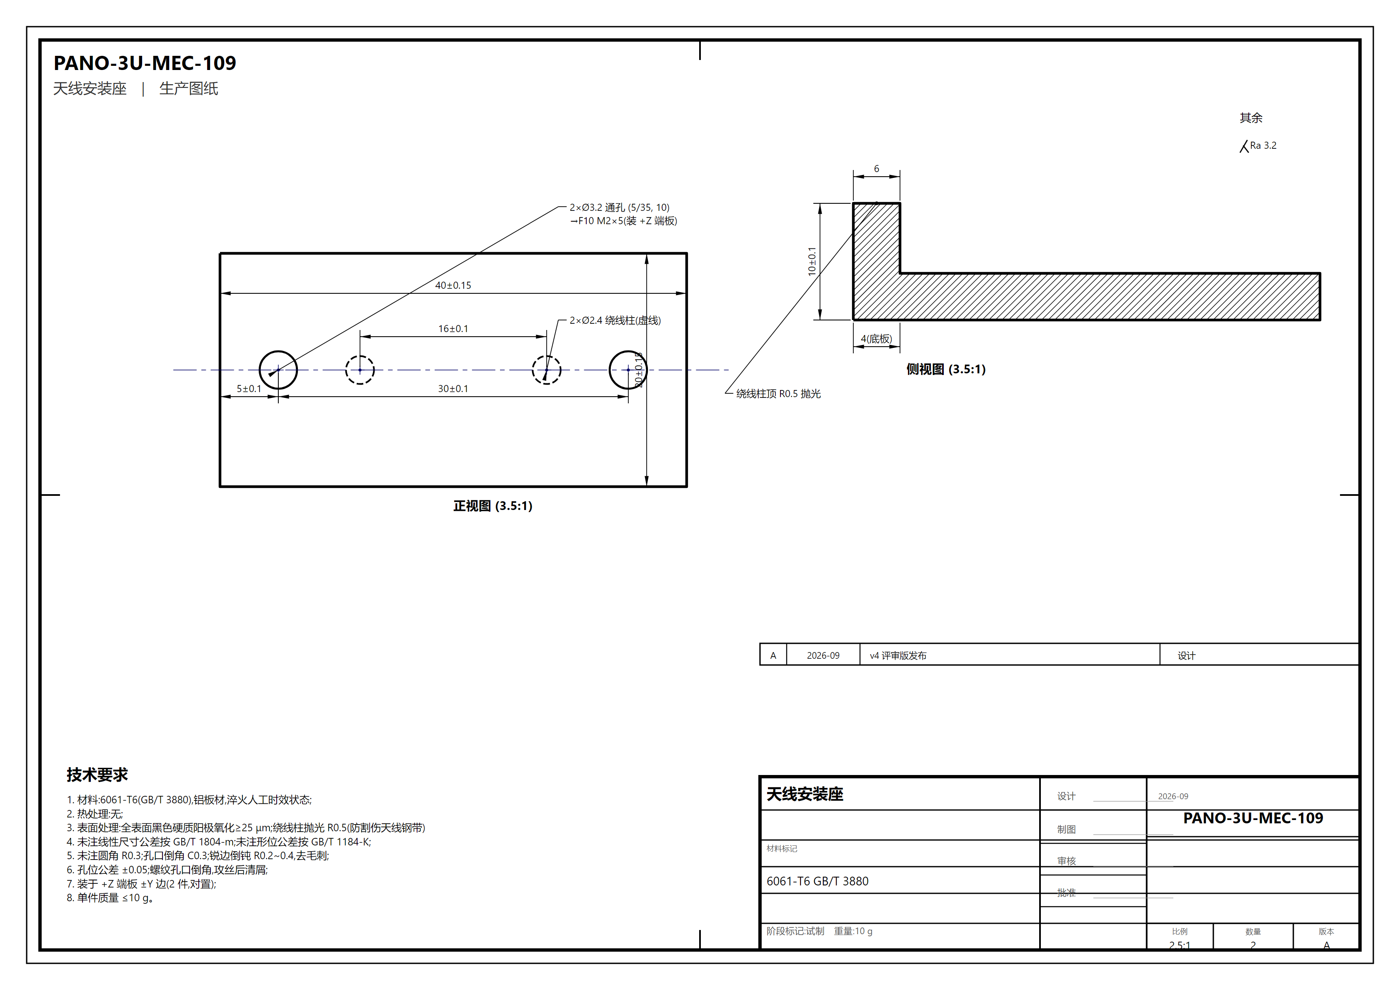
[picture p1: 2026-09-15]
03_生产图纸_GB23页/PNG/P12_MEC-109.png

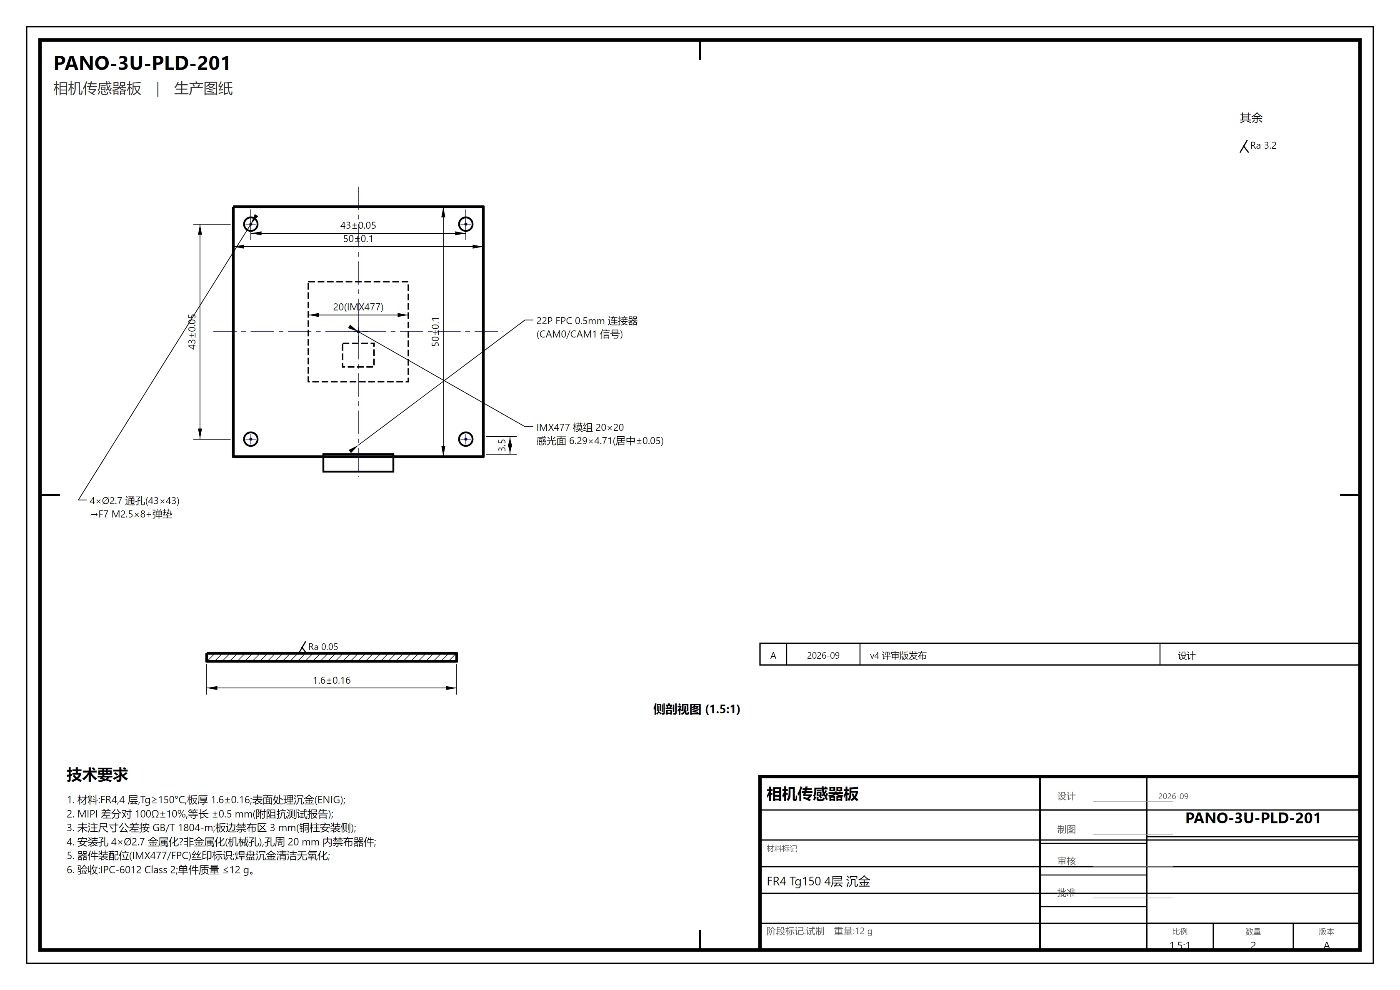
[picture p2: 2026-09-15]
03_生产图纸_GB23页/PNG/P14_PLD-201.png

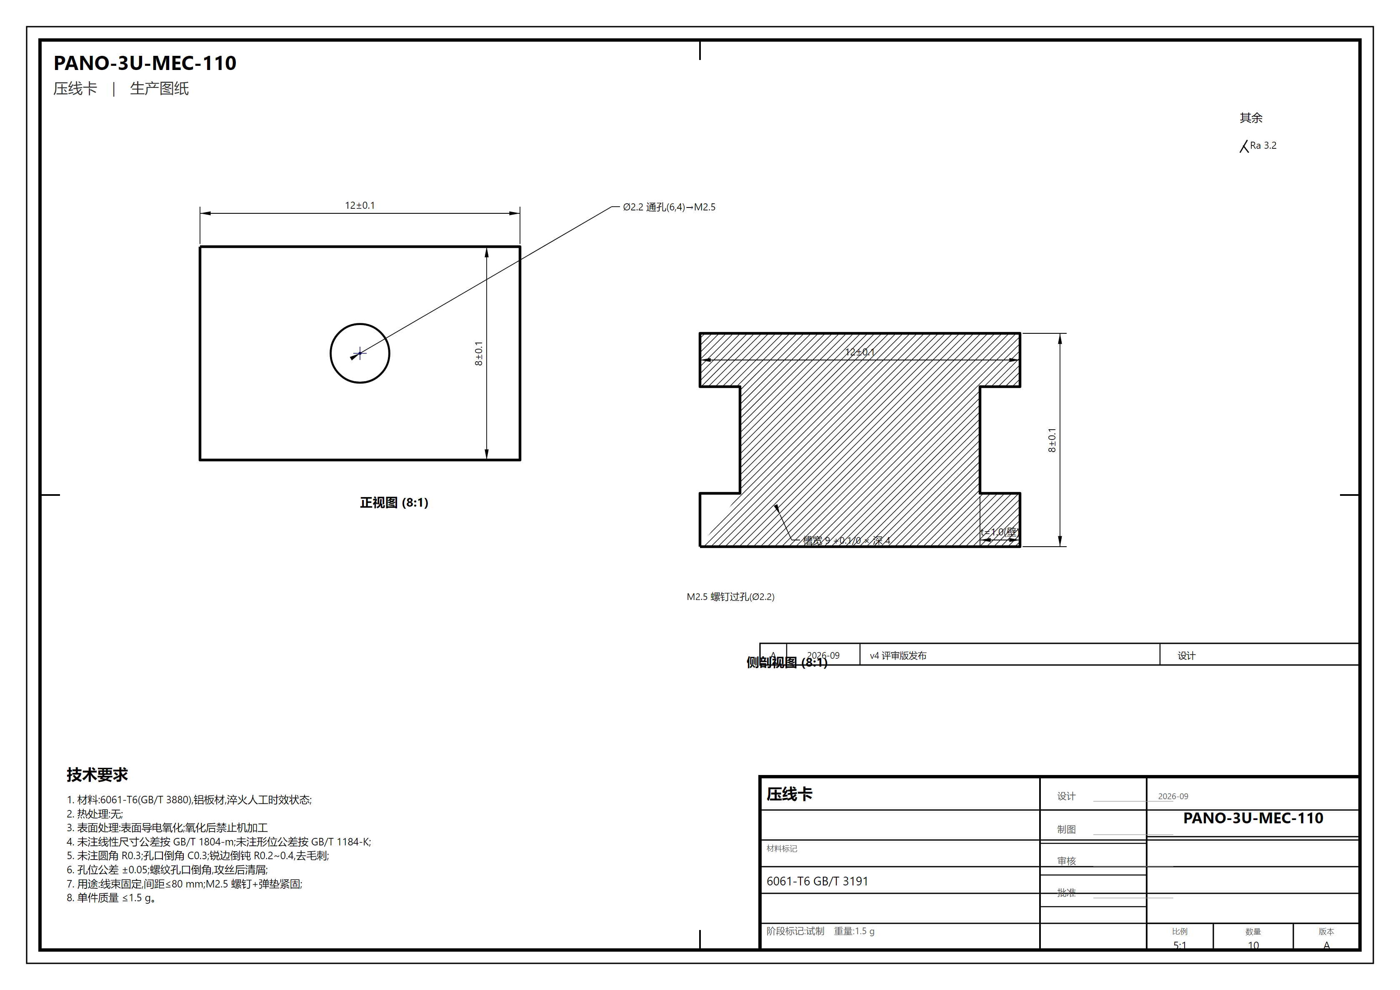
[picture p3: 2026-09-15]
03_生产图纸_GB23页/PNG/P13_MEC-110.png

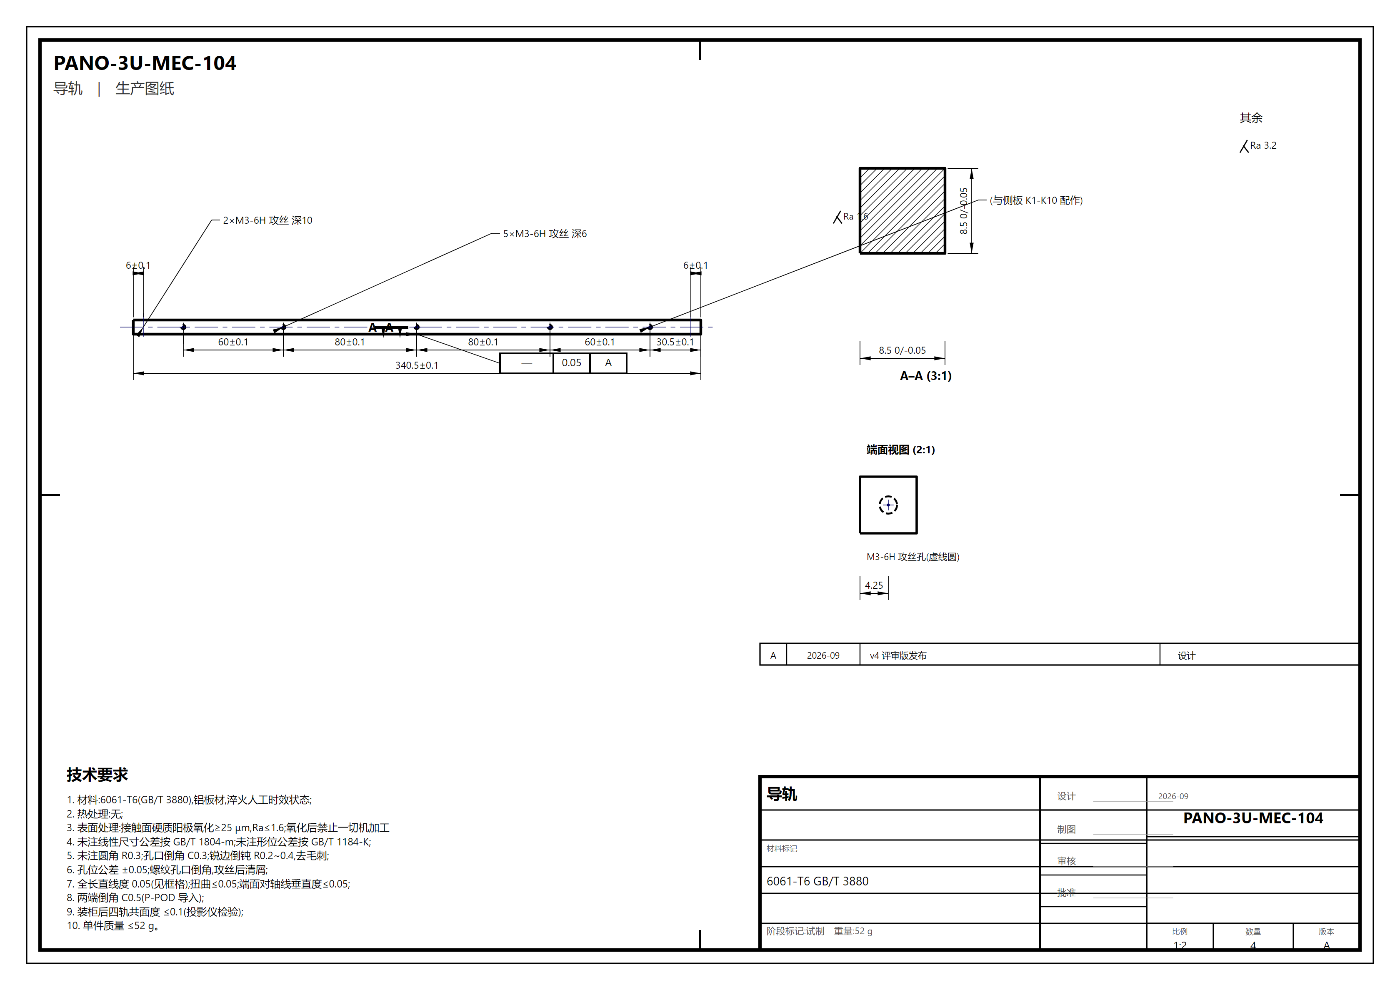
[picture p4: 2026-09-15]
03_生产图纸_GB23页/PNG/P6_MEC-104.png

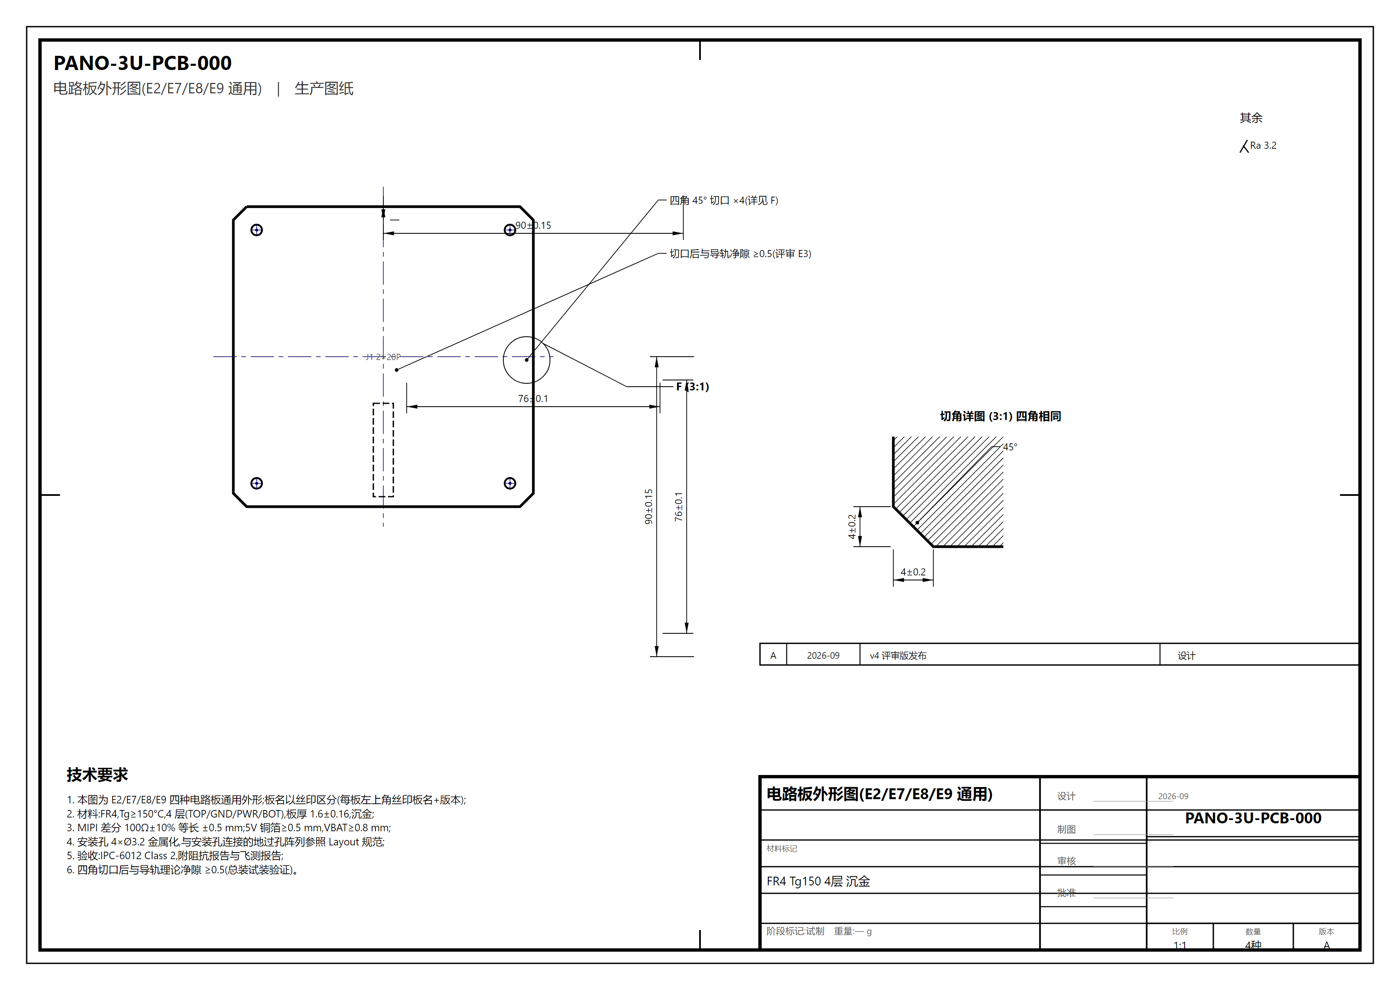
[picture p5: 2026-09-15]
03_生产图纸_GB23页/PNG/P15_PCB-000.png

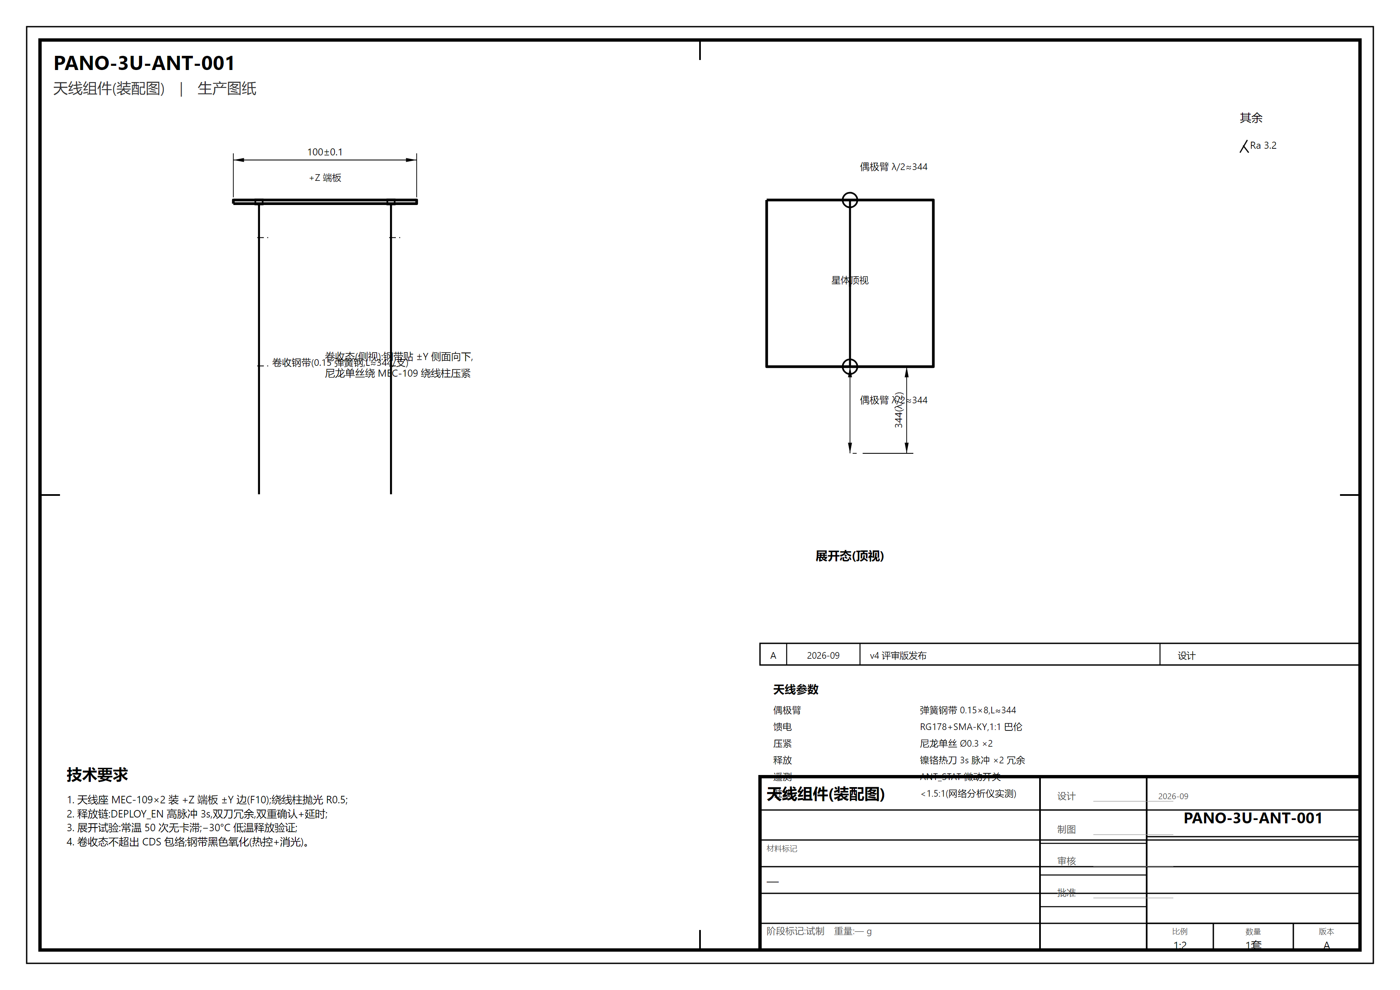
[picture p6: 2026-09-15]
03_生产图纸_GB23页/PNG/P20_ANT-001.png

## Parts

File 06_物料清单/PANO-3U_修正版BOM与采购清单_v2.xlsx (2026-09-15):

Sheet: 机加件
PANO-3U 修正版 BOM — 机加件(v2/投产版)
依据:DXF 加工文件 13 个 + 详细设计说明书 vC + 数据一致性核查报告 QA-001 | 2026-09
PANO-3U-MEC-102 | −Z 端板 | 6061-T6 | 100×100×2.0 | 1 | 黑色硬质阳极氧化≥25μm | 48 | S1-S3/R1 孔位公差±0.05(CDS 界面);R1 与 Ø6.35 销间隙 0.05-0.15 | —
PANO-3U-MEC-103A | 侧板-相机面(±X) | 6061-T6 | 340.5×83×1.5 | 2 | 贴片区导电氧化/其余黑色阳极氧化 | 92 | Ø26 相机窗+4×M2 攻丝深4;K1-K10 外表面 Ø6×90° 沉孔(沉头齐平);贴片区平面度≤0.2 | —
PANO-3U-MEC-103B | 侧板-普通面(±Y) | 6061-T6 | 340.5×83×1.5 | 2 | 贴片区导电氧化/其余黑色阳极氧化 | 96 | P1 Ø6 过线孔加护套;K 孔沉头朝外;贴片区平面度≤0.2 | —
PANO-3U-MEC-104 | 导轨 | 6061-T6 | 8.5×8.5×340.5 | 4 | 硬质阳极氧化 Ra≤1.6 | 52 | P-POD 界面关键件:直线度≤0.05/340,扭曲≤0.05;两端 C0.5;氧化后禁机加;CMM 抽检 | —
PANO-3U-MEC-105 | 中部隔板 | 6061-T6 | 90×90×1.5 | 3 | 导电氧化 | 28 | 四角 45° 切口(避导轨净隙≥0.5);中央 56×56;4×Ø3.2(76×76) | —
PANO-3U-MEC-106 | 电池支架(U型) | 6061-T6 | 70×40×25, t=1.5 | 2 | 导电氧化 | 35 | 折弯内 R1.5,90°±1°;内腔贴 1mm 绒毡;壁孔 4×Ø3.2 | —
PANO-3U-MEC-107 | 相机镜座 | 6061-T6 | Ø32×26 车件 | 2 | 黑色阳极氧化 | 18 | Ø22h6 止口与 MEC-111 Ø22H7 配作(间隙≤0.02);M14×0.5-6H 配作;通光孔发黑 | —
PANO-3U-MEC-108 | 分离开关支架 | 6061-T6 | 60×20×15, t=1.2 折弯 | 1 | 导电氧化 | 12 | 3×Ø4 开关孔位对准 −Z 端板 S1-S3;折弯内 R1.0 | —
PANO-3U-MEC-109 | 天线安装座 | 6061-T6 | 40×20×10 | 2 | 黑色阳极氧化 | 10 | 绕线柱抛光 R0.5(防割伤钢带) | —
PANO-3U-MEC-110 | 压线卡 | 6061-T6 | 12×8×6 | 10 | 导电氧化 | 1.5 | 卡线槽 9×深 4 | —
PANO-3U-MEC-111 | 相机支架(L型) | 6061-T6 | 34×34×15, t=2.0 | 2 | 导电氧化 | 16 | Ø22H7 沉孔对法兰面垂直度≤0.03;与 103A 窗配作 | v4 新增
铝材坯料 | 6061 板材/棒料 | 6061-T6 | 含加工余量 | 1批 | — | — | 板厚:t=1.2/1.5/2.0;棒料 Ø35(镜座) | —
【备件】 | 全套结构件备件(振动试验损耗) | — | — | 1套 | — | — | 按 BOM 数量+20% 投料 | —

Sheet: 紧固件与胶接
PANO-3U 修正版 BOM — 紧固件与胶接(v2)
单机数量=几何核算值;采购含 25% 备件 | F5/F4 数量修正依据 QA-001 A1
F2 | 内六角沉头螺钉 | M3×6 ISO 10642 | A2-70 | 40 | 50 | 1.0 N·m | Loctite 243 | 侧板↔导轨侧面(沉头与板面齐平) | —
F3 | 内六角盘头螺钉 | M3×6 GB/T 818 | A2-70 | 20 | 25 | 1.0 N·m | 弹垫 GB/T 93 | 堆栈板/隔板/支架固定 | —
F4 | 双通六角铜柱 | M3×15 | H62 镀镍 | 4 | 8 | 手紧+1/4圈 | Loctite 243 | E7↔E2 层距 | 数量修正:8→4(+备件)
F5 | 双通六角铜柱 | M3×12 | H62 镀镍 | 12 | 16 | 手紧+1/4圈 | Loctite 243 | E9↔E8↔MEC-105↔E7 三层层距(每层4根) | 数量修正:8→12(QA-001 A1)
F6 | 双通六角铜柱 | M3×10 | H62 镀镍 | 4 | 6 | 手紧+1/4圈 | Loctite 243 | 堆栈底座(−Z端板↔E9) | —
F7 | 内六角盘头螺钉 | M2.5×8 GB/T 818 | A2-70 | 8 | 10 | 0.5 N·m | 弹垫 M2.5 | 相机传感器板(4颗/机×2) | —
F8 | 内六角沉头螺钉 | M2×6 ISO 10642 | A2-70 | 8 | 10 | 0.3 N·m | Loctite 243 | 镜座↔MEC-111(4颗/座×2) | —
F9 | 内六角盘头螺钉 | M3×8 GB/T 818 | A2-70 | 8 | 10 | 1.0 N·m | 弹垫 | 电池支架↔隔板 | —
F10 | 内六角沉头螺钉 | M2×5 ISO 10642 | A2-70 | 6 | 8 | 0.3 N·m | Loctite 243 | 天线座/开关支架 | —
F11 | 平垫圈 | M3 GB/T 97.1 | A2 | 40 | 50 | — | — | F1/F3/F9 配用 | —
F12 | 弹簧垫圈 | M3 GB/T 93 | 65Mn | 28 | 35 | — | — | F3/F9 配用 | —
F13 | 尼龙锁紧螺母 | M3 GB/T 889 | A2 | 8 | 10 | 1.0 N·m | 自锁 | 电池支架贯穿螺栓 | —
F14 | 内六角盘头螺钉 | M2×8 GB/T 818 | A2-70 | 8 | 10 | 0.3 N·m | 弹垫 M2 | MEC-111↔MEC-103A(v4 新增) | —
G1 | 螺纹锁固胶 | Loctite 243 10ml | — | 1 | 2 | — | — | 全部螺纹连接(自锁螺母除外) | —
G2 | 瞬干胶 | Loctite 401 20g | — | 1 | 1 | — | — | 镜头调焦后点胶固定(三点) | —
G3 | 室温硫化硅橡胶 | GD414 / DC 3140 | — | 1 | 2 | — | — | 线束绑扎/连接器应力释放/滤光片点胶 | —
G4 | 导热硅脂 | 信越 G-751 | — | 1 | 1 | — | — | CM4↔导热垫↔散热块 | —
G5 | 结构胶带 | 3M 966 | — | 2 | 3 | — | — | 太阳电池片贴装 | —
G6 | 导电胶 | CW2400 | — | 1 | 1 | — | — | 电池片焊点补强(可选) | —
G7 | 绒毡 1mm | 聚酯 | — | 0.2 | 0.3 | — | — | MEC-106 内腔衬(防划伤电池) | v2 新增

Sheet: 电气电子
PANO-3U 修正版 BOM — 电气电子(v2)
采购属性:长周期≥8周/关键件(到货需检验)/自制 | 变更依据 QA-001
E2 | CM4 载板(自研) | 4层 90×90 沉金 Tg150 | 1 | DF40C-100DP+双22P CSI+TPS22965 | 自制投板 | 3 | —
E3 | 相机模组 | 树莓派 HQ Camera(IMX477) | 2 | 4056×3040 1.55μm | 长周期 | 3 | —
E4 | 鱼眼镜头 | M12×0.5 f1.4 F2.4 FOV≥195° | 2 | 等距投影;须索取畸变曲线表 | 关键件(实测收口) | 4 | —
E5 | IR-cut 滤光片 | 650nm Ø8×0.55 双面AR | 2 | 贴镜座后端 | 市场件 | 4 | —
E6 | 存储卡 | 工业级 microSD 512GB(-25~+85°C) | 1 | Swissbit/金士顿工业级 | 关键件 | 2 | —
E7 | OBC 主控板(自研) | 4层 90×90 | 1 | STM32F405+W25Q128+TPS3823+DS3231 | 自制投板 | 3 | —
E8 | EPS 电源板(自研) | 4层 90×90 | 1 | LT3652×4+TPS2557(CM4 3A)+TPS2553×3 | 自制投板 | 3 | U20=TPS2557(勿错贴 TPS2553)
E9 | UHF 通信板(自研) | 4层 90×90 | 1 | DRF4463+1W PA+SAW;57.6kbps 默认 | 自制投板 | 3 | 速率默认 57.6k
E10 | IMU | MPU-9250(停产)→BMI270+IST8310 | 1 | SPI/I2C 9轴 | 停产风险-替代 | 1 | R3:二选一
E11 | 磁强计 | QMC5883L 模块 | 1 | I2C 0x0D;远离磁力矩器≥40mm | 市场件 | 2 | —
E12 | 温度传感器 | DS18B20 不锈钢封装 | 6 | 1-Wire;电池2/相机2/板卡2 | 市场件 | 8 | —
E13 | 磁力矩器驱动 | DRV8837 模块 | 3 | PWM;限流 0.8A | 市场件 | 4 | —
E14 | 磁力矩器线圈 | Ø0.35 漆包线 500匝×2+PCB平面线圈×1 | 1套 | 0.2 A·m²/轴;自绕 | 自制 | 1套+备线 | —
E15 | 电池 | NCR18650B 3400mAh | 4 | 2S2P=7.4V/6.8Ah/49Wh;原厂正品渠道 | 关键件(防假) | 6 | —
E16 | 电池保护板 | 2S BMS(DW01+8205) 5A | 1 | 过充/过放/短路 | 市场件 | 2 | —
E17 | 电池加热膜 | 聚酰亚胺 5V/3W 40×40 背胶 | 2 | KSD9700 温控串联 | 市场件 | 3 | 功率修正:2W→3W(QA-001 A2)
E18 | 温控开关 | KSD9700 5°C闭合/8°C断开 | 2 | 250V/5A 加热回路 | 市场件 | 3 | —
E19 | 太阳电池片 | Maxeon Gen3 切割片 22.6×34 | 72 | 0.256W/片 BOL;±Y 20S1P/±X 16S1P | 长周期(进口) | 78 | —
E20 | 旁路二极管 | SS34 SMA | 8 | 每串 2 只;40V/3A | 市场件 | 12 | —
E21 | 分离开关 | 微动开关 SPDT 接NC 滚轮压杆 3A | 3 | 压紧=断开/弹出=闭合 | 市场件 | 5 | —
E22 | RBF 组件 | Ø6.35 插销+常开微动开关 | 1 | 插入=断电(地面) | 市场件 | 1 | —
E23 | 板间连接器 | 2.54mm 镀金车针 2×20P | 4 | 堆栈贯通总线 | 市场件 | 6 | —
E24 | 线缆连接器 | JST SH/XH 带锁 2P/4P/6P | 30 | — | 市场件 | 36 | —
E25 | 射频连接器 | SMA-KY + RG178 | 2 | 50Ω | 市场件 | 3 | —
E26 | 相机排线 | 22P 0.5mm FPC 异面 200/300mm | 2 | MIPI CSI;贴铜箔屏蔽 | 市场件 | 3 | —
E27 | 导线 | 28AWG PTFE 20m + 22AWG 5M(M22759) | 1批 | — | 市场件 | 1批 | —
E28 | 天线 | 弹簧钢带 0.15 自制偶极×2+热刀线+尼龙丝 | 1套 | L≈344mm/支 | 自制 | 2套 | —
E29 | PCB 制造 | 4层 FR4 Tg150 1oz 沉金 90×90 | 8 | 4种×2(含备) | 投板 | 12 | IPC-6012 Class 2
E30 | SMT 贴片 | 含钢网 | 4 | — | 代工 | 4 | IPC-A-610 Class 2
E31 | 三防漆 | 丙烯酸(可选) | 1 | 连接器遮蔽 | 市场件 | 1 | —
E32 | 扎带/套管/热缩管 | PTFE 扎带+热缩管 | 1批 | — | 市场件 | 1批 | —
E33 | M12→CS 转接环 | M12×0.5 转 CS(1"-32) | 2 | HQ 相机装 M12 鱼眼 | 市场件 | 3 | —
E34 | MLI 多层隔热组件 | 双面镀铝聚酯膜 10 层+衬布,包覆电池组 | 1 | 冷工况修订(仿真 S3) | 自制/外协 | 2 | v2 新增(QA-001 A3)

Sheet: v2修正记录
PANO-3U 数据一致性核查记录(QA-001 摘要)
A=阻断生产须先修正;B=文档不同步;D=已验证一致 | 详细见 QA-001 报告
A2 | 高(BOM 缺修订) | E17 电池加热膜 5V/2W,但仿真 S3 冷工况修订要求 3W(否则电池 −21°C 低于 0°C 充电禁限),说明书 §5 已改 3W | 仿真报告 S3 + 说明书 §5 vs BOM E17 | E17 规格 5V/3W 40×40 | BOM
A3 | 高(BOM 缺项) | 电池包 MLI 多层隔热组件为冷工况修订必需件,BOM 无此项 | 仿真报告 S3 修订 + 说明书 §5 | 新增 E34 MLI 组件(外协制作 2 件) | BOM
B1 | 中(文档) | KiCad README 写"TPS2553×4 电子保险丝",原理图 U20 已改 TPS2557(核对 eps.kicad_sch:TPS2557×1) | eps.kicad_sch grep | 更新 README 文案;投板以原理图为准 | KiCad README
B2 | 中(参数) | 数传默认速率:说明书/仿真定值 57.6 kbps;电子规格书 §3 与固件 comm.c 仍为 9.6 kbps(9600) | xcheck 脚本 | 规格书更新;固件默认参数改 57600(联调时配置) | 规格书、固件
B3 | 中(软件对接) | 评审 R6 称固件已有 DEPLOY_DELAY_S 参数,源码中无此常量(deploy 延时逻辑存在但命名不同);J1 信号名 WD_KICK/HEAT_EN 与固件命名未对齐 | fw_check 脚本 grep | 软件在环联调(C 类 C6)时统一命名 | 固件、评审报告
D1 | 已验证 ✓ | DXF 13 个与说明书孔位坐标表全一致(H1-H16/S1-S3/R1/C1/K1-K10/相机窗/隔板切口/压线卡等) | DXF 解析 vs 说明书 §2.2-2.3 | — | —
D2 | 已验证 ✓ | TPS2557 已入原理图与 BOM(E4 关闭确认) | grep eps.kicad_sch | — | —
D3 | 已验证 ✓ | receiver.py KISS 帧 frame[16:] 修复已存在(R1 关闭确认;frame[16:-2] 仅存于 AX.25 有 FCS 分支,属正确逻辑) | receiver.py | — | —
D4 | 已验证 ✓ | 质量三处一致:说明书 2.83kg = 结构报告 v4 = 仿真 S0(2359g+20%) | 三文件 | — | —
D5 | 已验证 ✓ | 紧固件 F2=40(4面×2轨×5点)、F9=8、F13=8、分离开关3、太阳片72+备6 与几何一致 | 几何核算 | — | —

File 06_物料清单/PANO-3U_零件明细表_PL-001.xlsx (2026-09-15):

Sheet: 机加件零件明细
PANO-3U 零件明细表 PL-001 — 机加/结构件
航天级分级:关键件(失效危及任务/安全)/重要件(失效降级)/一般件 | 数量=单机+备件 | 引用图纸=生产图纸册 23 页 | 批次管理:机加件逐件打标识序号
序 | 图号 | 名称 | 材料/标准 | 规格(mm) | 单机 | 备件 | 表面处理 | 分级 | 图页 | 检验要求
1 | PANO-3U-MEC-101 | +Z 端板 | 6061-T6 GB/T 3880 | 100×100×2.0 | 1 | 2 | 黑色硬质阳极氧化≥25μm | 重要件 | P2 | IQC 100%投影+CMM 抽检
2 | PANO-3U-MEC-102 | −Z 端板 | 6061-T6 GB/T 3880 | 100×100×2.0 | 1 | 2 | 黑色硬质阳极氧化≥25μm | 关键件(分离界面) | P3 | IQC 100%投影;S/R 孔位专检
3 | PANO-3U-MEC-103A | 侧板-相机面 | 6061-T6 GB/T 3880 | 340.5×83×1.5 | 2 | 4 | 贴片区导电氧化/其余黑硬氧 | 关键件(相机基准) | P4 | 窗位/同轴配作检验
4 | PANO-3U-MEC-103B | 侧板-普通面 | 6061-T6 GB/T 3880 | 340.5×83×1.5 | 2 | 4 | 贴片区导电氧化/其余黑硬氧 | 重要件 | P5 | IQC 100%投影
5 | PANO-3U-MEC-104 | 导轨 | 6061-T6 GB/T 3880 | 8.5×8.5×340.5 | 4 | 5 | 硬质阳极氧化 Ra≤1.6 | 关键件(P-POD 界面) | P6 | CMM 100%直线度;膜厚抽检
6 | PANO-3U-MEC-105 | 中部隔板 | 6061-T6 GB/T 3880 | 90×90×1.5 八角 | 3 | 4 | 导电氧化 | 重要件 | P7 | IQC;试装间隙≥0.5
7 | PANO-3U-MEC-106 | 电池支架 | 6061-T6 GB/T 3880 | 折弯 40×70×25,t1.5 | 2 | 3 | 导电氧化+内衬绒毡 | 重要件 | P8 | 角度/孔位/绒毡贴合
8 | PANO-3U-MEC-107 | 相机镜座 | 6061-T6 GB/T 3191 棒料 | Ø32×26 车件 | 2 | 3 | 黑阳极氧化;通光孔发黑 | 关键件(相机基准) | P9 | 止口配作≤0.02;跳动≤0.02;螺纹通止规
9 | PANO-3U-MEC-108 | 分离开关支架 | 6061-T6 GB/T 3880 | 折弯 42×60×15,t1.2 | 1 | 2 | 导电氧化 | 关键件(分离安全) | P11 | 3×Ø4 对 S1-S3;行程实测
10 | PANO-3U-MEC-109 | 天线安装座 | 6061-T6 GB/T 3191 | 40×20×10 | 2 | 3 | 黑色阳极氧化 | 一般件 | P12 | 绕线柱 R0.5
11 | PANO-3U-MEC-110 | 压线卡 | 6061-T6 GB/T 3191 | 12×8×6 | 10 | 12 | 导电氧化 | 一般件 | P13 | IQC 抽检
12 | PANO-3U-MEC-111 | 相机支架 | 6061-T6 GB/T 3880 | 34×34,支柱 Ø6×12 | 2 | 3 | 导电氧化 | 关键件(相机基准) | P10 | 垂直度≤0.03;与窗配作
13 | PANO-3U-PLD-201 | 相机传感器板 | FR4 Tg150 4层 沉金 | 50×50×1.6 | 2 | 3 | ENIG | 重要件 | P14 | 阻抗报告;IMX477 位置±0.05
14 | PANO-3U-PCB-000 | 电路板外形(E2/E7/E8/E9) | FR4 Tg150 4层 沉金 | 90×90×1.6 | 各1 | 各2 | ENIG | 重要件 | P15 | IPC-6012 Class2;切口试装

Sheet: 标准件与电气件分级
标准件与电气件分级明细(摘要,全量见 BOM v2)
关键件/重要件实行批次追溯与加严检验;一般件按常规 IQC
编号 | 名称/规格 | 标准/型号 | 单机 | 备件 | 分级 | 加严要求
F2 | M3×6 沉头螺钉 | ISO 10642 A2-70 | 40 | 50 | 关键件(共面齐平) | 力矩 marking 100%
F9/F13 | M3×8+尼龙锁母 | GB/T 818/889 | 8 | 10 | 重要件 | 电池夹紧,防松验证
F5/F4/F6 | M3 双通铜柱 12/15/10 | H62 镀镍 | 20 | 16+8+6 | 重要件 | 堆栈层序与导通
E15 | NCR18650B 电池 | Panasonic 原厂 | 4 | 6 | 关键件(安全) | 内阻配对/防爆袋/TVAC
E19 | 太阳电池片 72 | Maxeon Gen3 | 72 | 78 | 重要件 | 隐裂零接受;I-V 逐串
E21 | 分离开关 NC | 滚轮压杆 SPDT | 3 | 5 | 关键件(CDS) | 四状态实测(A9 停检)
E1/E3 | CM4/相机 | Raspberry Pi | 3 | 5 | 重要件(商质) | 72h 老炼筛选;上电检验
E4 | 鱼眼镜头 | M12 f1.4/F2.4 | 2 | 4 | 关键件(成像) | 畸变表随件;实测 C2
E6 | 工业 microSD 512G | 宽温 −25~+85 | 1 | 2 | 重要件 | 上电读写验证

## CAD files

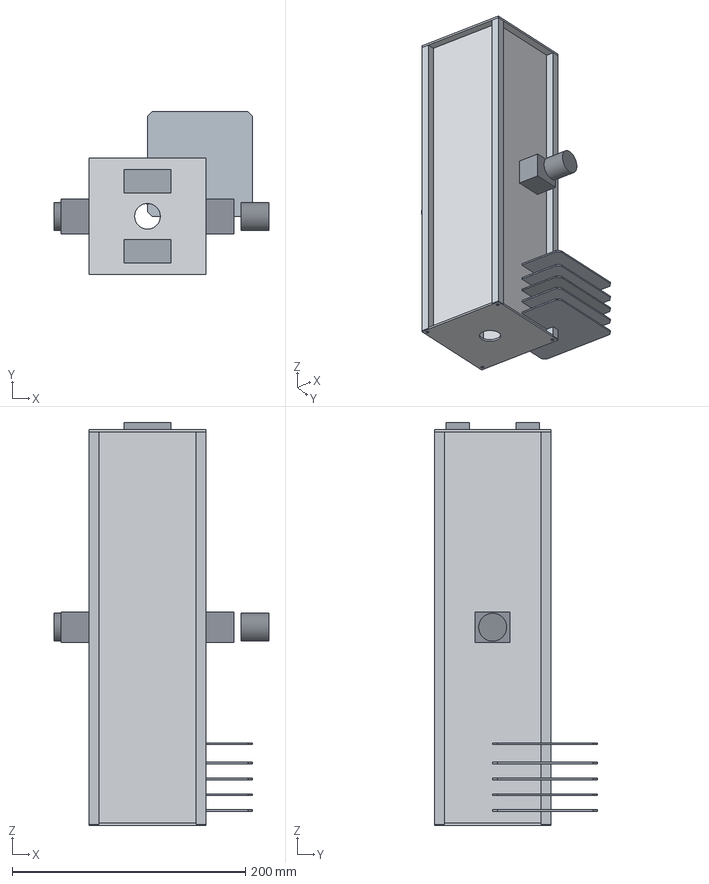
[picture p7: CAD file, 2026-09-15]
04_三维模型_STEP/装配/PANO-3U-ASM-001_整星装配.step
184.0 x 140.0 x 345.5 mm
MEC-101_+Zç«¯æ¿ x 2
MEC-104_å¯¼è½¨1 x 4
MEC-103A_+Xä¾§æ¿ x 2
MEC-103B_+Yä¾§æ¿ x 2
E9_UHF x 4
MEC-105_éæ¿
ç¸æºæ¨¡ç»_+X x 2
éå¤´_+X x 2
MEC-109_å¤©çº¿åº§+Y x 2

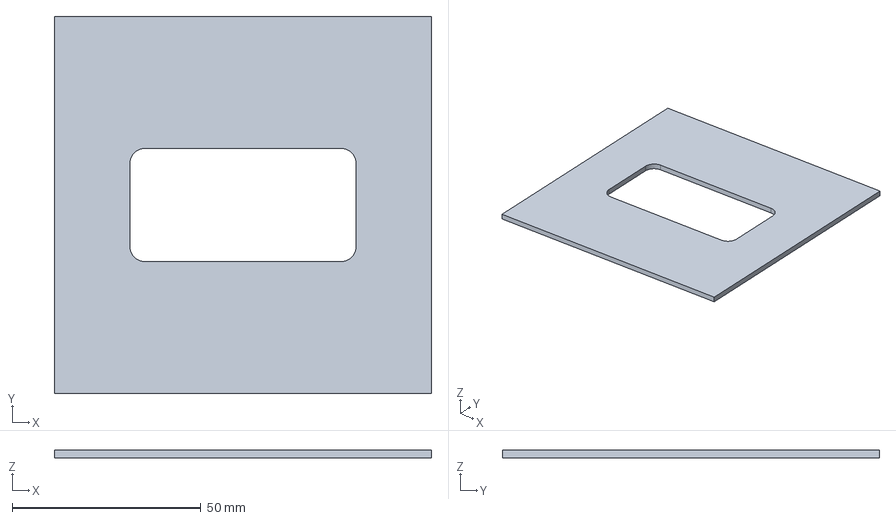
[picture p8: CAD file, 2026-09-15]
04_三维模型_STEP/零件/PANO-3U-MEC-101_+Z端板.step
100.0 x 100.0 x 2.00 mm

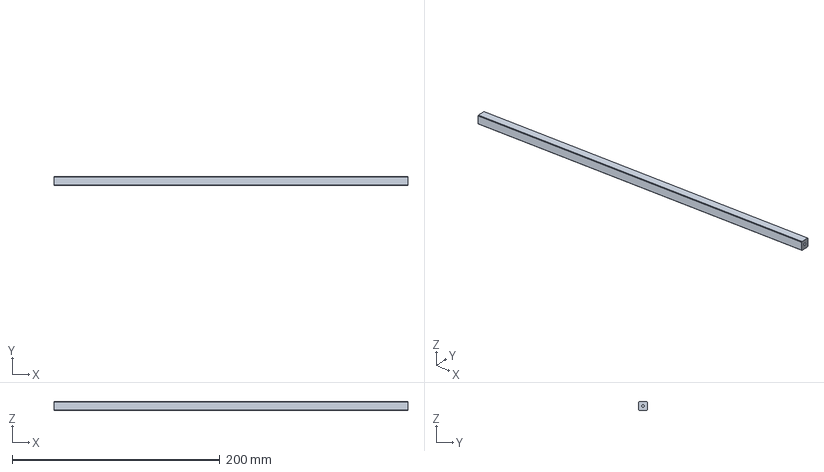
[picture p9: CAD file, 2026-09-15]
04_三维模型_STEP/零件/PANO-3U-MEC-104_导轨.step
340.5 x 8.50 x 8.50 mm

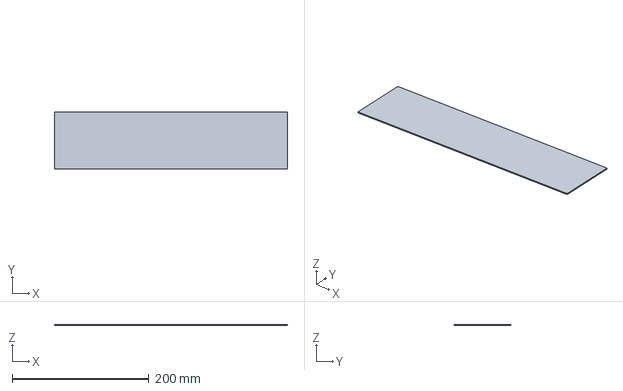
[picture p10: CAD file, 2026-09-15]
04_三维模型_STEP/零件/PANO-3U-MEC-103A_相机面_侧板.step
340.5 x 83.0 x 1.50 mm

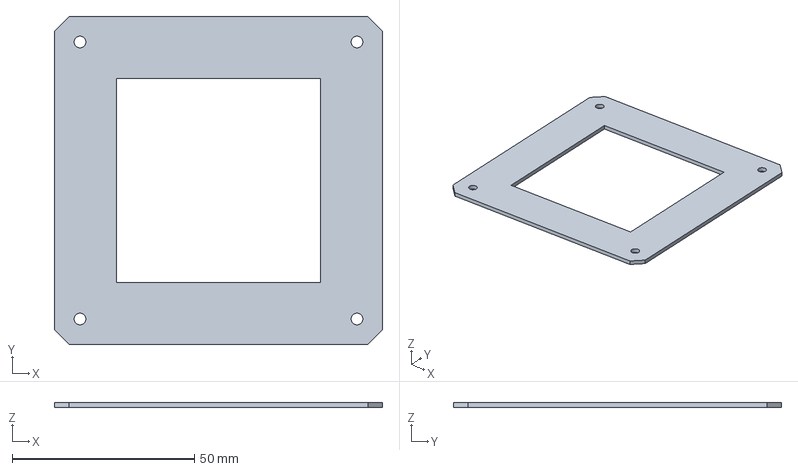
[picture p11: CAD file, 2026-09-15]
04_三维模型_STEP/零件/PANO-3U-MEC-105_中部隔板.step
90.0 x 90.0 x 1.50 mm

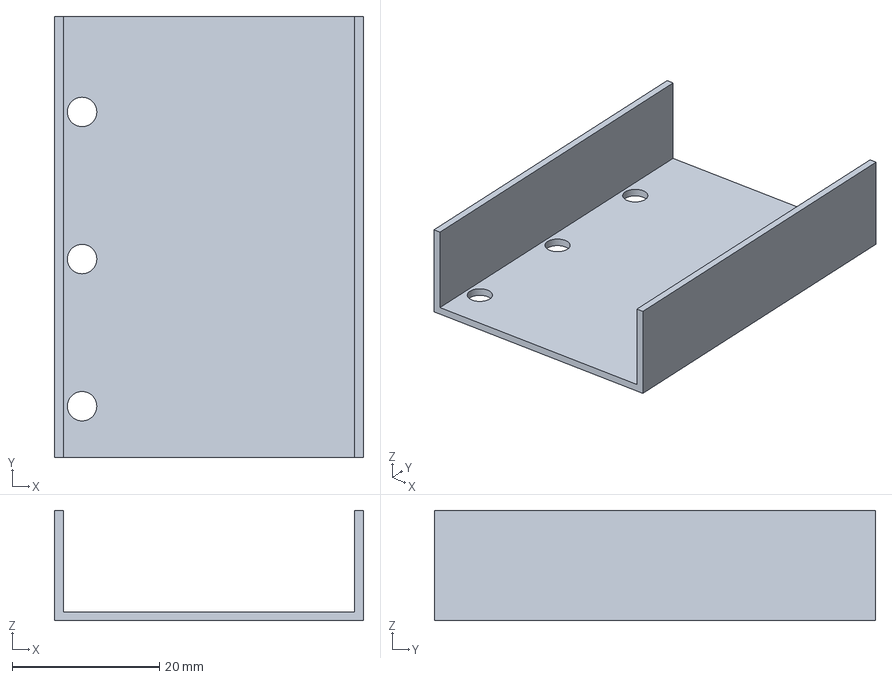
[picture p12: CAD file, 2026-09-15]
04_三维模型_STEP/零件/PANO-3U-MEC-108_分离开关支架.step
42.0 x 60.0 x 15.0 mm

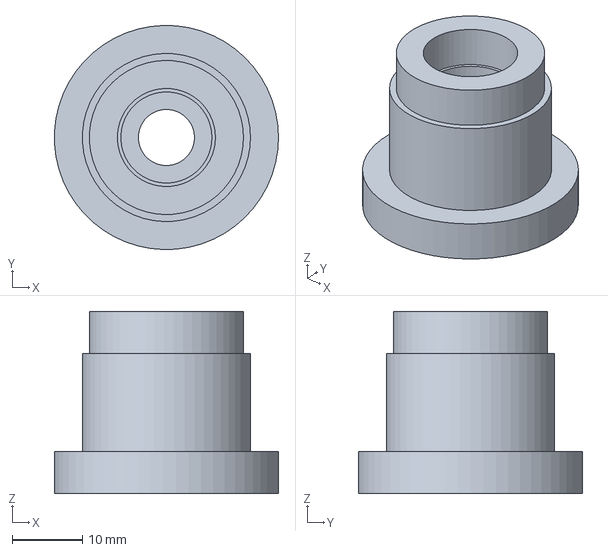
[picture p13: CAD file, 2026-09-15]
04_三维模型_STEP/零件/PANO-3U-MEC-107_相机镜座.step
32.0 x 32.0 x 26.0 mm

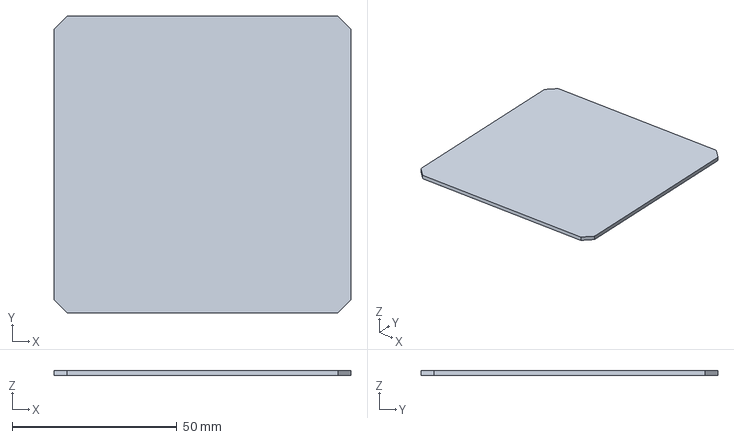
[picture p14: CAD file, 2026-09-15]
04_三维模型_STEP/零件/PANO-3U-PCB-000_电路板外形.step
90.0 x 90.0 x 1.60 mm

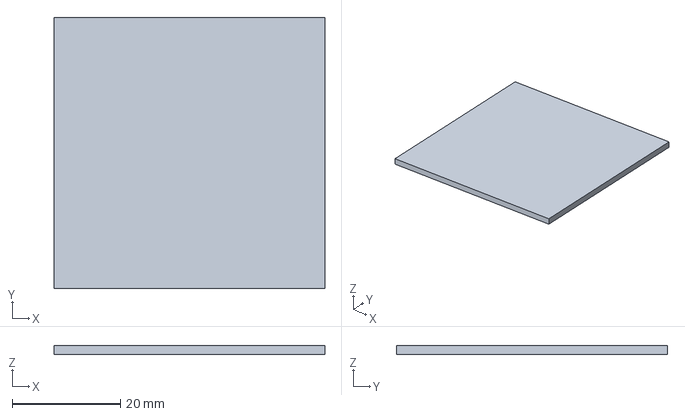
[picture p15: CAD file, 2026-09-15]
04_三维模型_STEP/零件/PANO-3U-PLD-201_相机传感器板.step
50.0 x 50.0 x 1.60 mm

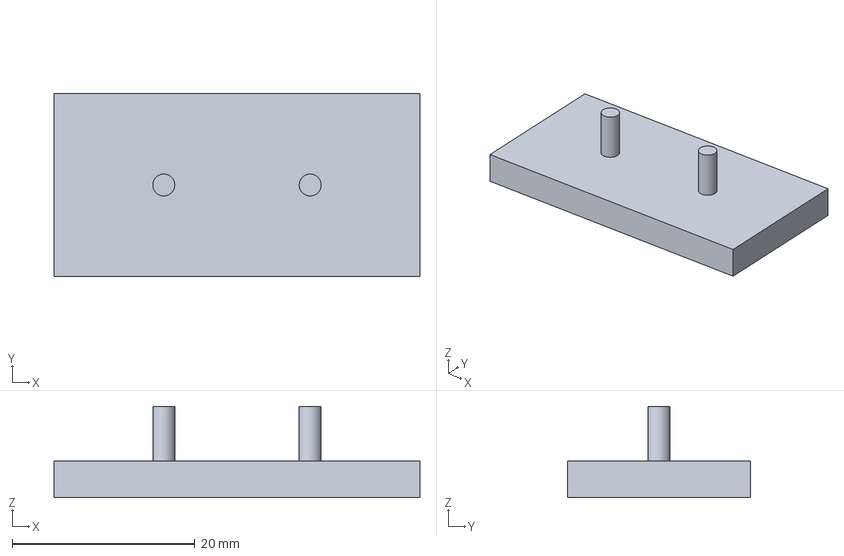
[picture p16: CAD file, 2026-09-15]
04_三维模型_STEP/零件/PANO-3U-MEC-109_天线安装座.step
40.0 x 20.0 x 10.0 mm

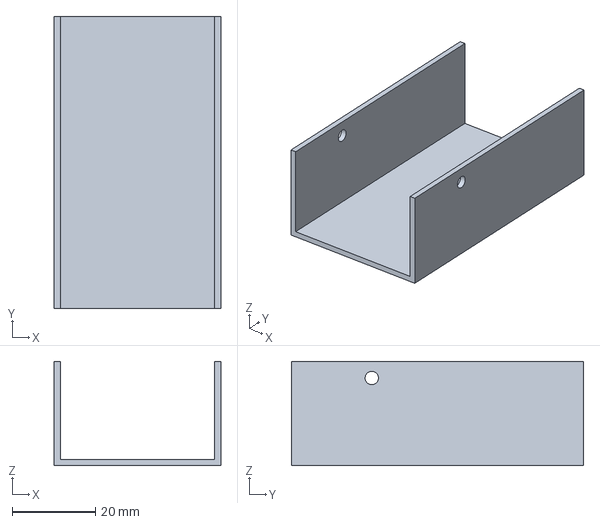
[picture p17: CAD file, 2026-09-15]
04_三维模型_STEP/零件/PANO-3U-MEC-106_电池支架.step
40.0 x 70.0 x 25.0 mm

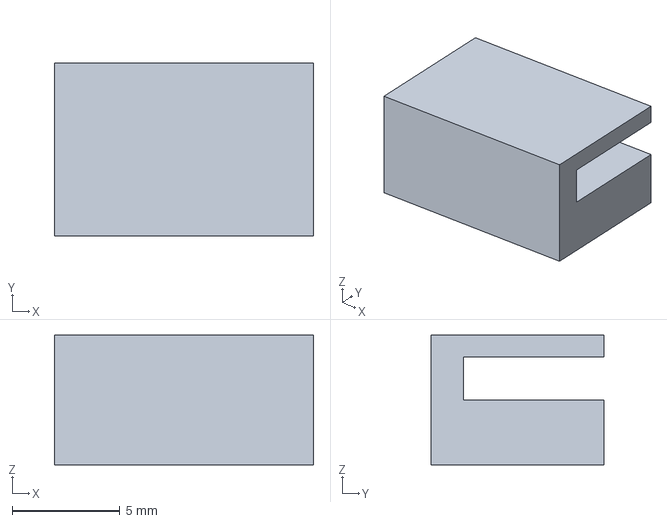
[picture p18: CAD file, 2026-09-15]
04_三维模型_STEP/零件/PANO-3U-MEC-110_压线卡.step
12.0 x 8.00 x 6.00 mm

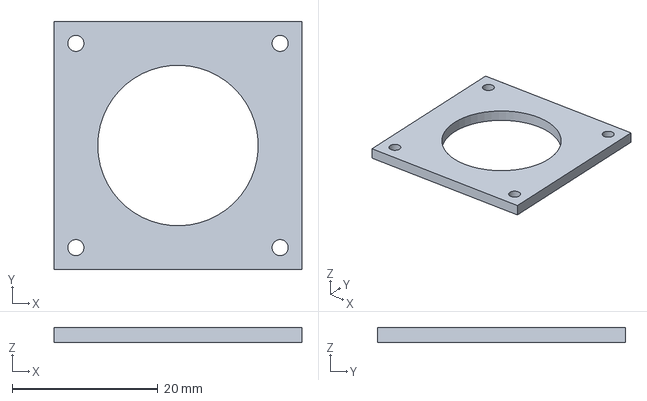
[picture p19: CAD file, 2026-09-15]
04_三维模型_STEP/零件/PANO-3U-MEC-111_相机支架.step
34.0 x 34.0 x 2.00 mm

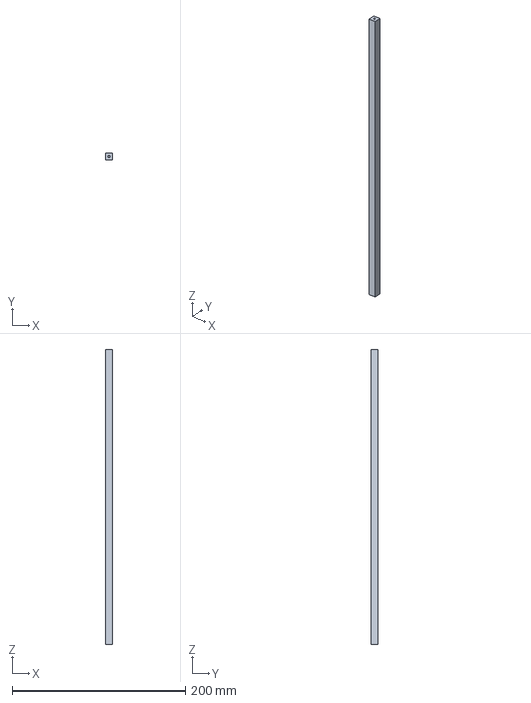
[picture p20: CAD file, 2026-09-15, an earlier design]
99_归档/01_原始设计资料/STEP模型/MEC-104_导轨.step
8.50 x 8.50 x 340.5 mm

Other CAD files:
04_三维模型_STEP/零件/PANO-3U-MEC-102_-Z端板.step
04_三维模型_STEP/零件/PANO-3U-MEC-103B_普通面_侧板.step
99_归档/01_原始设计资料/图纸/DXF加工文件/PANO-3U-MEC-101_正Z端板.dxf
99_归档/01_原始设计资料/STEP模型/MEC-110_压线卡.step
99_归档/01_原始设计资料/STEP模型/MEC-101_正Z端板.step
99_归档/01_原始设计资料/STEP模型/MEC-102_负Z端板.step
99_归档/01_原始设计资料/STEP模型/MEC-103_侧板.step
99_归档/01_原始设计资料/STEP模型/MEC-105_中部隔板.step
99_归档/01_原始设计资料/STEP模型/MEC-106_电池支架.step
99_归档/01_原始设计资料/STEP模型/MEC-107_镜座.step
99_归档/01_原始设计资料/STEP模型/MEC-108_分离开关支架.step
99_归档/01_原始设计资料/STEP模型/MEC-109_天线安装座.step
99_归档/01_原始设计资料/STEP模型/PANO-3U-MEC-111_相机支架.step
99_归档/01_原始设计资料/STEP模型/PANO-3U_整星装配体.step
99_归档/01_原始设计资料/图纸/DXF加工文件/MEC-103A_侧板相机面.dxf
99_归档/01_原始设计资料/图纸/DXF加工文件/MEC-103B_侧板普通面.dxf
99_归档/01_原始设计资料/图纸/DXF加工文件/MEC-111_相机支架.dxf
99_归档/01_原始设计资料/图纸/DXF加工文件/PANO-3U-MEC-102_负Z端板.dxf
99_归档/01_原始设计资料/图纸/DXF加工文件/PANO-3U-MEC-104_导轨.dxf
99_归档/01_原始设计资料/图纸/DXF加工文件/PANO-3U-MEC-105_中部隔板.dxf
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

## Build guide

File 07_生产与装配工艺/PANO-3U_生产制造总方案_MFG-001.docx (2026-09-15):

PANO-3U 双鱼眼全景立方星

(3U CubeSat · 500km SSO 全景成像任务)

生产制造总方案

制造策略 · 工艺路线 · 质量控制 · 风险与开放项

文档编号 | PANO-3U-MFG-001
版本 | v1.0(投产版)
编制日期 | 2026-09
编制 / 审核 / 批准 | / /
分发 | 制造 / 质量 / 采购 / 试验

# 1 概述

## 1.1 目的与范围

本方案规定 PANO-3U 双鱼眼全景立方星(3U,100.0×100.0×340.5 mm,质量 2.83 kg)从零组件制造、单板投产、组件装配到整星环境试验全过程的制造策略、工艺路线、质量控制与放行条件,是全套生产文件的顶层文件。配套文件:《数据一致性与制造性核查报告》(QA-001)、《装配工艺规程》(WI-001)、《检验与试验规范》(QT-001)、《修正版 BOM 与采购清单 v2》、图纸册(22 页 A3 线稿)与 DXF 加工文件 13 个。

## 1.2 产品制造基线

项目 | 基线 | 说明
设计版本 | 版本 C(图纸 v4 评审修订版) | 评审报告 E1-E6 已全部关闭
结构文件 | DXF ×13 + 图纸册 22 页 + STEP 装配体 | 几何经 QA-001 与说明书逐项核对一致
电气文件 | KiCad 工程(4 板)+ 电子系统设计规格书 | U20=TPS2557 已入原理图;README 待更新(B1)
BOM | 修正版 v2(本包) | 修正 A1 铜柱数量 / A2 加热膜 3W / A3 新增 MLI
软件 | 载荷软件(pytest 6/6)+ OBC 固件 + 地面站 | C6 联调项开放
质量/质心 | 2.83 kg(干重 2.36 kg+20%);质心 z=146.7 mm | 三文件一致(D4)
合规 | Cal Poly CDS Rev.14 | 端面无凸起;侧面凸起仅镜头 6.0≤6.5 mm

## 1.3 制造总体策略

按"工艺验证件 → 鉴定件(QM)→ 飞行件(FM)"三阶段推进:(1)阶段 A 以工艺验证为目的,投制全套结构件 1 套(含 20% 备料)与 PCB 打样贴片 1 套,完成来料检验、试装配与关键工艺(氧化配合、沉头齐平、相机锁焦、太阳片焊接)验证,不装太阳电池片与电池,不进入环境试验;(2)阶段 B 以鉴定为目的,用工艺验证件合格品总装 1 颗鉴定星,完成全项功能测试与鉴定级振动、热真空试验;(3)阶段 C 依据鉴定件暴露问题修订工艺后投产飞行件,并保留全套结构件备件 1 套。飞行件与鉴定件的差异仅限:替换经验胀或寿限考核的电池、太阳片按 EOL 参数复验。

依据《设计评审报告》结论:"可投入结构件与 PCB 打样,不建议直接投产飞行件"——本方案的三阶段划分即为对该结论的落实;飞行件放行前置条件见第 7 节。

# 2 编制依据

序号 | 文件 | 版本 | 来源
1 | PANO-3U 详细设计说明书 | vC | 原始资料包
2 | PANO-3U 电子系统设计规格书 | vB | 原始资料包
3 | PANO-3U 设计评审报告(错误与风险清单) | v1 | 原始资料包
4 | PANO-3U 结构力学校核报告(+v4 补遗) | vB | 原始资料包
5 | PANO-3U 全套仿真数据报告(S0-S7) | v1 | 原始资料包
6 | 3U 全景立方星全套图纸 v4 评审修订版(18 页)/ 总装图纸 v4(3 页) | v4 | 原始资料包
7 | DXF 加工文件 13 个 | v4 | 原始资料包
8 | PANO-3U_全级 BOM 清单 | v1 | 原始资料包(本包已修正为 v2)
9 | KiCad 工程 + 投板前核对清单 / 软件包 + 研制测试顺序 | vB | 原始资料包
10 | 数据一致性与制造性核查报告 | QA-001 v1.0 | 本包
11 | Cal Poly CubeSat Design Specification Rev.14 | — | 公开发布

# 3 制造分工与工艺路线

## 3.1 分工矩阵

工作包 | 内容 | 承担方式 | 关键控制
结构件机加 | MEC-101~111 共 12 种 24 件(+20% 备料) | 外协 CNC(三轴+车床)+ 折弯 | 首件三坐标全检;氧化外协
表面处理 | 黑色/硬质/导电阳极氧化、化学导电钝化 | 外协氧化厂 | 膜厚≥25μm(涡流仪抽检);氧化后禁机加
PCB 制造 | E2/E7/E8/E9 四种 4 层板 | 外协板厂 | IPC-6012 Class 2;阻抗报告
SMT 贴片 | 四板贴片(含 0402/MSOP/QFN) | 外协代工 | IPC-A-610 Class 2;首件检验
电缆网 | W1-W14 下线/压接/标识 | 自制 | 下线表;通断/绝缘测试
太阳阵 | 72 片切割片互连+贴片 | 自制(洁净台) | 焊接温度≤380°C;贴片位置±0.5
总装 | A1-A12 工序(WI-001) | 自制 | 力矩/胶接/清洁度;见证点
环境试验 | 振动 + 热真空 | 高校共享平台(预算 2 万) | 试验大纲见 QT-001

## 3.2 机加件工艺路线

图号 | 工艺路线 | 关键工序控制 | 检验
MEC-101/102 端板 | 下料(6061 板 t2.0)→ CNC 铣外形/孔 → 去毛刺(C0.3/锐边 R0.2)→ 阳极氧化(黑,硬质≥25μm) | 孔位±0.05;沉孔/通孔同轴度≤0.05;氧化后禁止一切机加工 | 投影仪全检孔位;涡流测膜厚
MEC-103A/B 侧板 | 下料(t1.5)→ CNC 铣外形/窗/孔 → 窗口倒角 0.3×45°(内侧)→ 沉孔 → 3M966 贴片区遮蔽 → 分区氧化 | 贴片区导电氧化不染色;沉孔在外表面;M2 攻丝深 4 攻后清屑 | 孔位投影;贴片区平面度≤0.2
MEC-104 导轨 | 下料(8.5×8.5 方料 or 铣方)→ 精铣四面(0/-0.05)→ 端面 C0.5 → 攻丝(M3 深10/深6)→ 硬质阳极氧化 | 全长直线度≤0.05/340;扭曲≤0.05;氧化后禁机加 | CMM 抽检直线度;Ra≤1.6
MEC-105 隔板 | 下料(t1.5)→ CNC 铣八角外形+56×56 窗+4 孔 → 导电氧化 | 四角 45° 切口与导轨配间隙≥0.5(试装) | 试装验证
MEC-106 电池支架 | 下料(t1.5)→ CNC/冲外形与孔 → 折弯×2(R1.5,90°±1°)→ 导电氧化 → 内腔贴绒毡 | 折弯线距孔≥6;回弹补偿试折 | 角度/孔位检验
MEC-107 镜座 | 车床:车外圆 Ø32 → 车止口 Ø22h6 → 镗内腔 → 车内螺纹 M14×0.5-6H → 切 IR-cut 槽 → 发黑(通光孔) | 与 MEC-111 沉孔配作(间隙≤0.02);与镜头/转接环配作 | 螺纹通止规;止口跳动≤0.02
MEC-108/109/110 | 下料 → CNC/折弯 → 氧化 →(109)绕线柱抛光 R0.5 | 3×Ø4 与端板 S1-S3 位置对准 | 试装对准验证
MEC-111 相机支架 | 下料(t2.0)→ 铣外形/沉孔 Ø22H7 → 支柱车削组合 → 导电氧化 | 沉孔对法兰垂直度≤0.03;与 103A 窗配作 | 同轴度检具

## 3.3 PCB 投板与贴片要求

项目 | 要求 | 依据
板厚/层数 | 1.6 mm,4 层(FR4 Tg150):TOP-SIG/GND/PWR-BOT | 电子系统设计规格书
表面处理 | 沉金(ENIG);阻焊绿色(或按设计) | —
外形 | 90×90 mm,四角 45° 切口(去 |x|>41 且 |y|>41);4×Ø3.2(76×76)金属化? | 评审 E3;QA-001 D1
阻抗 | MIPI 差分对 100 Ω±10%,等长 ±0.5 mm;附阻抗测试报告 | KiCad 核对清单
线宽 | 5 V 走线≥0.5 mm 或敷铜;VBAT≥0.8 mm | KiCad 核对清单
验收 | IPC-6012 Class 2;附飞针/测试点报告 | 本方案 §5
贴片 | IPC-A-610 Class 2;首件 X-ray/QC;BGA/QFN 需 X-ray 抽检 | —
特别提示 | E8 板 U20 必须 TPS2557(勿贴 TPS2553);U21-U23 为 TPS2553 | 评审 E4/QA-001

# 4 关键工艺与控制点(KCP)

KCP | 工艺 | 失控后果 | 控制措施 | 类型
KCP-1 | 导轨/端板氧化后机加 | P-POD 接触面破坏→对接卡滞 | 工艺卡红字标注;氧化件入专柜;下道工序交接检查 | 停检点
KCP-2 | 相机窗与镜座同轴装配 | 成像偏心/视场缺失 | 三级定位链配作;装后用平行光管/远靶检查像圆居中 | 见证点
KCP-3 | 镜头锁焦 | 全星照片离焦返工(须开舱) | 1.5 m 标靶 MTF 中心最优;Loctite 401 三点点胶;静置 24 h 复测 | 停检点
KCP-4 | 太阳片焊接 | 隐裂→在轨功率衰减 | 烙铁≤380°C、单点≤3 s;戴指套;焊后 10 倍放大查裂纹;逐串测 I-V | 见证点
KCP-5 | 力矩紧固 | 振动松动/滑丝 | 校准力矩螺丝刀(半年内);对角分两次(50%→100%);拧后漆笔 marking | 见证点
KCP-6 | 胶接固化 | 结构强度不足 | Loctite 243/401 按说明固化;GD414 24 h;固化期内禁止加力 | 见证点
KCP-7 | 分离开关行程 | 舱内带电(拒载)或分离后不上电 | 装 P-POD 模拟块实测:压入 0.5-1.0 mm 断开;弹出闭合;万用表在线监测 | 停检点
KCP-8 | 电池组焊接 | 内短路/热失控 | 点焊镍片(禁烙铁长时间);装防爆袋;内阻配对(≤20 mΩ 差);绝缘复测 | 停检点
KCP-9 | 线束敷设 | 磨损短路/天线卡滞 | 分束≥10 mm;压线卡每 80 mm;过孔护套;RF 分支;摇动复测通断 | 见证点
KCP-10 | 母线-结构绝缘 | 在轨供电异常 | 贴片后/总装后各测一次≥10 MΩ(500 V 兆欧表) | 见证点

# 5 质量控制计划

检验点按"来料检验(IQC)—过程检验(PQC)—最终检验(FQC)—试验"四级设置:IQC 依据 QT-001 第 2 节,机加件 100% 尺寸(孔位投影仪)+外观+膜厚抽检;PCB 到货核对阻抗报告与外观;关键电气件(CM4/相机/电池/太阳片)逐件通电或内阻检验。PQC 在 WI-001 各工序卡内定义自检与互检项。FQC 为整星检验(见 QT-001 第 4 节)。全部检验记录形成质量数据包,随星交付。

阶段 | 检验点 | 内容 | 判据 | 记录
A 阶段 | IQC-机加 | 外形/孔位/平面度/膜厚/直线度 | 图纸公差;MEC-104 直线度≤0.05 | IQC 报告+CMM 报告
A 阶段 | 试装配 | 端板-导轨-侧板框架;隔板/PCB 缺口试装;间隙≥0.5 | 无干涉、无强行装配 | 试装记录
A 阶段 | 关键工艺验证 | KCP-2/3/4 各完成 1 次全流程 | 锁焦复测 MTF;太阳串 I-V 达标 | KCP 验证报告
B 阶段 | FQC | 整星检验(QT-001 §4) | 全项通过 | FQC 报告
B 阶段 | 环境试验 | 振动+热真空(QT-001 §5) | 频率衰减<5%;TVAC 功能正常 | 试验报告
C 阶段 | 飞行件放行 | A 类问题闭环 + C1-C6 收口 + 鉴定件数据评审 | 放行评审通过 | 放行评审纪要

# 6 制造资源与环境

- 设备:CNC 三轴(外协)、数控车床(镜座)、折弯机(106/108)、CMM 三坐标(导轨/端板抽检)、投影仪(孔位)、涡流测厚仪(氧化膜厚)、回流焊/SMT 线(外协)、恒温洁净台(太阳阵/相机)、500 V 兆欧表、校准力矩螺丝刀(0.3-1.0 N·m 三把)、万用表、示波器、SDR 链路测试台。
- 环境:电子装配与太阳阵作业在 ESD 防护区(腕带+垫+湿度 40-60%RH);太阳片焊接区洁净度万级;相机锁焦区避振、无尘;总装区禁止金属屑/切削液残留(装配前机加件全部清洗)。
- 耗材:Loctite 243/401、GD414、导热垫(1 mm,6 W/m·K)、3M 966、PTFE 扎带、尼龙单丝、镍片(电池点焊)。

# 7 风险、开放项与飞行件放行条件

编号 | 开放项 | 责任/方式 | 时点 | 对投产的影响
C1 | FEA 复核(模态+随机振动,ANSYS/NASTRAN) | 外协/高校,输入=STEP 装配体(网格 2 mm,导轨绑定,PCB 质量点) | 阶段 A 并行 | 解析法已全部 SF≥28,飞行件放行前置条件
C2 | 镜头实物验证(真实 FOV/畸变/等距偏差) | 采购样片实测;>3% 偏差用 5 阶多项式(管线已支持) | 阶段 A(与采购同步) | 镜头采购到货即测;不阻断结构件
C3 | 辐照 TID 摸底(30 krad 级) | 关键页依赖 W25Q128 冗余+看门狗复位链;必要时第三方辐照 | 阶段 B | 1 年 LEO 任务风险可接受,记录余量
C4 | 热真空 TVAC(−20~+50°C 四循环) | 含镜头侧日照局部 +45°C 验证;电池 −12~+8°C 复测 | 阶段 B 鉴定试验 | 热修订(MLI+3W+NTC)以 TVAC 收口
C5 | EMC 自兼容 + 437 MHz 频率许可 | PA 发射时 IMU/磁强计读数比对;按发射商办理执照 | 阶段 B | 执照为发射前置
C6 | 软件在环联调 | payload_read_chunk() 占位实现、HDLC 位填充简化、CAM1 2-lane 4K30 带宽实测、J1 信号命名统一(B3) | 阶段 A/B | 不阻断硬件投产,阻断出厂

飞行件(FM)放行条件(全部满足):(1)QA-001 A 类问题修正件到位并复验;(2)阶段 A 关键工艺验证报告通过;(3)鉴定件振动+热真空试验通过且偏离项归零;(4)C1 FEA 报告通过、C2 镜头实测闭环;(5)C6 软件联调通过;(6)C5 频率许可取得;(7)质量数据包齐全。

# 8 项目计划与里程碑

阶段 | 周次 | 里程碑/交付 | 前置条件
A-1 | W1-W2 | 结构件投料(CNC 外协下单)、PCB 投板、长周期器件下单(CM4/相机/电池/太阳片) | BOM v2 定版、检查清单签署
A-2 | W3-W4 | 结构件到货 IQC;氧化外协;CMM 抽检报告 | —
A-3 | W5-W6 | PCB 到货+SMT 贴片;镜头/太阳片到货检验;C2 镜头实测 | —
A-4 | W7-W8 | 试装配+关键工艺验证(KCP-2/3/4);阶段 A 评审 | A-2/A-3 合格
B-1 | W9-W12 | 鉴定件总装(A1-A12);FQC;C6 软件联调 | 阶段 A 评审通过
B-2 | W13-W14 | 振动鉴定试验+复测 | FQC 通过;C1 FEA 报告
B-3 | W15-W16 | 热真空四循环+老炼 72h;鉴定数据包评审 | B-2 通过;C4 大纲确认
C-1 | W17+ | 飞行件投产(按鉴定偏离归零后的工艺);C5 频率许可 | 鉴定评审通过
C-2 | W21+ | 飞行件总装+验收试验+出厂评审 | 全部放行条件(§7)

进度按周次计,实际以长周期器件(CM4 约 8-12 周、太阳片 4-6 周)到货为准;外协工序(CNC/氧化/SMT/试验)需在下单时同步排期并确认档期。

# 9 投制前检查清单(发行前签署)

# | 检查项 | 结果

1 | DXF 13 个为 v4 版(103A/103B 分开、105 带缺口、111 新增),与图纸册 22 页一致 | □
2 | BOM v2 已替代原 BOM:F5×12/F4×4、E17 3W、新增 E34 MLI | □
3 | 氧化要求区分:硬质(101/102/104)/黑色(101/102/107/109)/导电(103 贴片区/105/106/108/110/111) | □
4 | E8 板 U20=TPS2557 投板 BOM 高亮;U21-23=TPS2553 | □
5 | 镜头采购合同含"提供畸变曲线表"条款;备件+1 | □
6 | CM4/相机/电池/太阳片长周期项已下单(提前 8-12 周) | □
7 | 力矩螺丝刀校准证书在有效期;CMM/投影仪可用 | □
8 | 氧化厂确认硬质 25μm/导电氧化工艺与禁再加工交检要求 | □
9 | 环境试验平台档期(振动+TVAC)已预约 | □
10 | 本方案、QA-001、WI-001、QT-001 已签署分发 | □

PANO-3U-MFG-001 生产制造总方案 v1.0(投产版)

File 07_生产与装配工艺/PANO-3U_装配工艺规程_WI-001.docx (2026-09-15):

PANO-3U 双鱼眼全景立方星

(3U CubeSat · 500km SSO 全景成像任务)

装配工艺规程

A1–A12 工序卡 · 力矩/胶接/清洁度/检验细则

文档编号 | PANO-3U-WI-001
版本 | v1.0
编制日期 | 2026-09
编制 / 审核 / 批准 | / /
分发 | 制造 / 质量 / 采购 / 试验

# 1 通用要求

## 1.1 人员与环境

- 装配人员经本规程培训并考核;关键工序(KCP-2/3/4/7/8)由指定熟练人员操作。
- 电子装联与太阳阵作业在 ESD 防护区进行:腕带+防静电台垫+离子风机,湿度 40-60%RH。
- 进入总装的所有机加件必须完成清洗(无切削液/金属屑残留),氧化件佩戴手套操作。
- 装配区禁止同时进行机械加工;总装台面铺软质垫,工具分区定位。

## 1.2 工具与计量

工具 | 规格 | 校准要求
力矩螺丝刀 | 0.1-1.0 N·m 可调,三把(0.3/0.5/1.0 档) | 半年内校准证书;使用前空载校验
烙铁 | 恒温 380°C(太阳片),280°C(导线) | 温度计校验;接地电阻<2Ω
万用表/兆欧表 | 四位半;500 V 兆欧表 | 年检合格
CMM/投影仪 | 用于 IQC | 年检合格

## 1.3 紧固件通用规则

- 全部螺纹连接涂 Loctite 243(尼龙锁紧螺母 F13 除外);涂胶位置螺栓尾部 2-3 扣。
- 对角顺序分两次拧紧:先 50% 力矩,再 100%;力矩值见表 1-1。
- 拧紧后立即用记号笔做见证标记(螺钉头-基面连线);振动试验后全数复查标记。
- 弹垫(F12)与平垫(F11)按 BOM v2 配用,顺序:螺钉→弹垫→平垫→被连接件。
- M2/M2.5 螺钉滑丝即报废更换,禁止反复拆装超过 3 次。

表 1-1　紧固件力矩表(完整版见 BOM v2)

编号 | 规格 | 力矩 | 防松 | 位置
F1 | M3×8 圆柱头 | 1.0 N·m | 243 | 端板↔导轨端面
F2 | M3×6 沉头 | 1.0 N·m | 243 | 侧板↔导轨侧面
F3 | M3×6 盘头 | 1.0 N·m | 弹垫 | 堆栈/隔板/支架
F4/F5/F6 | M3 铜柱 15/12/10 | 手紧+1/4 圈 | 243 | 堆栈层距
F7 | M2.5×8 盘头 | 0.5 N·m | 弹垫 | 相机传感器板
F8 | M2×6 沉头 | 0.3 N·m | 243 | 镜座↔支架
F9 | M3×8 盘头 | 1.0 N·m | 弹垫+F13 | 电池支架↔隔板
F10 | M2×5 沉头 | 0.3 N·m | 243 | 天线座/开关支架
F14 | M2×8 盘头 | 0.3 N·m | 弹垫 | 相机支架↔侧板

# 2 装配工序卡(A1–A12)

总装顺序自内向外:堆栈→电池舱→相机→端板合拢→外部附件→太阳阵→线束。每工序执行"自检+互检",停检点(H)须经质检确认后方可流转。

## A1 框架组装(导轨+端板) 【见证点 W】

前置:IQC 合格的端板×2、导轨×4、F1×8;清洗完成

材料与工装:力矩螺丝刀 1.0 N·m、Loctite 243、记号笔、软垫台面

操作步骤:

A1.1　将 4 根导轨直立,−Z 端板扣合于导轨端面(注意 S1/S2/S3/R1 孔位方位:R1 位于 (−45.75, +30))。

A1.2　导轨端面 M3 攻丝孔对准端板 H1-H4(±45.75),试拧 F1 全部 8 孔(先不涂胶)。

A1.3　退出 F1,涂 Loctite 243 后正式拧紧:对角顺序 50%→100%,力矩 1.0 N·m,共 4 角。

A1.4　翻身装 +Z 端板,重复。形成 100×100×340.5 框架。

A1.5　用刀口尺检查导轨共面(四面各检查一次),目视端板与导轨无缝隙。

质量控制:力矩 marking 全数;四轨对边平行度目视≤0.1;记录于 A1 卡。若导轨与端板间隙>0.05,查毛刺。

## A2 侧板安装 【见证点 W】

前置:A1 框架;MEC-103A×2 / 103B×2(贴片区朝外);F2×40

材料与工装:力矩螺丝刀、243、攻丝专用保护塞(防切屑入内)

操作步骤:

A2.1　确认侧板方位:103A(带 Ø26 窗)装 ±X 面,窗中心位于 Z=170;103B 装 ±Y 面。

A2.2　侧板 K1-K10 孔对准导轨侧面攻丝孔;先装下部 5 点再上部 5 点。

A2.3　F2 沉头螺钉涂 243 拧紧 1.0 N·m;沉头必须与板外表面齐平(低于表面≤0.05)。

A2.4　四面完成后检查侧板与端板贴合缝。

质量控制:沉头齐平逐点检查(指甲刮过无台阶);marking;窗孔方位复核(照光确认)

## A3 电气堆栈装配 【见证点 W】

前置:PCB 四板(E9/E8/E7/E2)+ MEC-105×1(堆栈用 1 块)+ 铜柱 F6×4/F5×12/F4×4 + 排针 E23×4

材料与工装:力矩螺丝刀、243、防静电镊子、万用表

操作步骤:

A3.1　−Z 端板内侧 H13-H16(±38)位置拧入 F6(M3×10)手紧+1/4 圈,涂 243。

A3.2　放 E9 通信板(元件面朝 +Z),四孔穿 F6,板上再拧 F5(M3×12)×4 手紧+1/4 圈。

A3.3　依序叠装:E8 EPS → F5 → MEC-105 隔板 → F5 → E7 OBC → F4(M3×15)×4 → E2 CM4 载板;各板 J1 排针全 40 位对插贯通,禁止错位强插。

A3.4　每层装机后目检排针无歪斜;四角铜柱高度一致(层距 12/12/12/15)。

A3.5　万用表测各板 GND 连通(≤0.3Ω)。

质量控制:层序核对(E9 在最下、E2 在最上);排针贯通;J1 各电源网络对地阻抗无短路。

## A4 隔板安装(其余两块) 【见证点 W】

前置:MEC-105×2(电池舱上下隔离/走线层)

材料与工装:F3×8、弹垫、力矩螺丝刀

操作步骤:

A4.1　电池舱区上下边界装隔板(z≈123 与 227 位置,随结构设计定位孔),四角 F3+弹垫 1.0 N·m。

A4.2　隔板 45° 切口方向对准导轨,确认与导轨间隙≥0.5。

质量控制:切口间隙塞尺抽检;marking。

## A5 电池组与电池舱 【停检点 H】

前置:E15×4(内阻配对≤20 mΩ 差)、BMS E16、镍片、热缩管、MEC-106×2、加热膜 E17×2、温控 E18×2、MLI E34

材料与工装:点焊机、防爆袋、内阻仪、绝缘手套、防火垫

操作步骤:

A5.1　电池 2S2P 组装:每侧 2 节并联(2P),跨侧串联(2S);点焊镍片,套热缩管。

A5.2　焊接在防爆袋内进行;焊后测开路电压(7.2-7.6 V)与内阻;绝缘复测。

A5.3　电池组装入 MEC-106 支架(内衬绒毡),抱箍 F9+F13 1.0 N·m。

A5.4　加热膜贴支架外壁,与 KSD9700 温控串联;引线接 J9。

A5.5　整组包覆 MLI 组件(E34),引线穿孔处衬套。

A5.6　【注意】电池组装区禁明火;完成前不得接入整星母线(经分离开关链,保持断电)。

质量控制:极性万用表复核;内阻/电压记录;加热回路通断(常温闭合)确认;绝缘≥10 MΩ。

## A6 相机模组装调(停检点) 【停检点 H】

前置:E3 相机×2、E4 镜头×2、E5 滤光片、E33 转接环、MEC-107/111、标靶 1.5 m

材料与工装:洁净台、平行光管或远靶、MTF 观察法(或拍摄判读)、Loctite 401、GD414

操作步骤:

A6.1　IR-cut 滤光片 GD414 点胶贴 MEC-107 后端面,静置 4 h。

A6.2　转接环拧入镜头,组合拧入镜座(M14×0.5),预锁。

A6.3　镜座止口 Ø22h6 压入 MEC-111 沉孔 Ø22H7,F8×4 固定 0.3 N·m;支架经 F14×4 装于侧板(0.3 N·m)。

A6.4　1.5 m 标靶实距调焦:中心 MTF 最优点锁焦,Loctite 401 三点点胶。

A6.5　静置 24 h 后复拍标靶判读,成像无漂移为合格。

A6.6　第二台相机同法。两机光轴分别沿 ±X,窗像圆居中。

质量控制:像圆居中(目视/判读);锁焦复测记录;F14/F8 力矩 marking。返工须重新标定。

## A7 相机组件装侧板 【见证点 W】

前置:A6 组件;若 A6 已含 F14 则本工序为复检

材料与工装:—

操作步骤:

A7.1　复核窗-镜座同轴(透光法);镜头前端面至侧板外表面距离≤6.0 mm(卡尺)。

A7.2　FPC 排线沿壁敷设至堆栈区,预留 CM4 插接长度,贴铜箔屏蔽。

质量控制:外伸 6.0 实测记录;FPC 无硬折。

## A8 端板合拢终拧 【见证点 W】

前置:A2 后的 +Z 端板(如未合拢)

材料与工装:力矩螺丝刀

操作步骤:

A8.1　+Z 端板对位(H1-H4 方位),F1×8 对角 50%→100% 终拧 1.0 N·m。

A8.2　全星紧固件 marking 专检(对照 BOM 数量清单逐点核对)。

质量控制:marking 100% 复查;包络复测 100×100×340.5。

## A9 分离开关与 RBF 安装 【停检点 H】

前置:MEC-108、微动开关×3(NC)、RBF 组件、F10×6

材料与工装:塞尺、P-POD 模拟压块、万用表

操作步骤:

A9.1　微动开关装 MEC-108 壁孔,滚轮对准 −Z 端板 S1/S2/S3;F10 固定。

A9.2　垫片调整滚轮压入行程 0.5-1.0 mm(P-POD 模拟块压入时触点断开)。

A9.3　万用表接 NC 回路:自然态导通,压入断开;三只串联全链验证。

A9.4　RBF 座装于端板 R1 位:插入=断开;拔除=闭合(但开关链仍断开,整星保持断电)。

A9.5　最终态验证:模拟发射链(拔 RBF+滚轮压入)= 全星断电。

质量控制:每种状态(自然/压入/RBF 插拔)回路通断记录 —— 本工序为 CDS 合规关键(KCP-7)。

## A10 太阳阵贴片 【见证点 W】

前置:E19 切割片 72+备、互连条、3M 966、SS34×8、JST 引线

材料与工装:洁净台、恒温烙铁≤380°C、指套、10 倍放大镜、I-V 测试源

操作步骤:

A10.1　侧板贴片区清洁(等离子/异丙醇),导电氧化面禁止打磨。

A10.2　按 SOL 图分段贴 3M 966,片间距 1.5 mm,位置±0.5。

A10.3　互连条焊接:单点≤3 s;焊后放大镜查隐裂;每 8 片串接 SS34 旁路二极管。

A10.4　逐串测 I-V(标称 0.45 A/串 @11.4V);贴引线经 103B P1 孔入舱(护套)。

A10.5　母线-结构绝缘 ≥10 MΩ(500 V)。

质量控制:I-V 记录逐串;隐裂零接受;绝缘记录。

A11 配套文件:线束下线表见生产图纸册 WIR-001(P22),下料长度按表并加 10% 现场余量。

## A11 天线与线束敷设 【见证点 W】

前置:E28 天线×2、天线座、热刀线、线束 W1-W14、压线卡×10、GD414

材料与工装:镊子、热风枪、通断表

操作步骤:

A11.1　天线座装 +Z 端板 ±Y 边(F10);钢带卷收贴 ±Y 侧面向下,尼龙丝绕绕线柱压紧。

A11.2　热刀线双刀冗余布线至 DEPLOY_EN 驱动。

A11.3　线束按下线表敷设:电源/信号/RF 分束≥10 mm;每 80 mm 压线卡;连接器插好后 GD414 应力释放。

A11.4　摇动测试:敷设完成后轻摇各线束,通断无变化。

质量控制:压线卡间距;分束间距;天线卷收态不超出包络。

## A12 整星终检与称重 【停检点 H】

前置:整星

材料与工装:天平(0.1 g)、质心测量工装、包络检具、兆欧表

操作步骤:

A12.1　外观终检:无划伤(膜层)、无多余物; photograph 留档。

A12.2　称重≤2.9 kg;质心 z=147±10 mm。

A12.3　包络 100×100×340.5 检具通过;端面无凸起;镜头外伸复测≤6.0。

A12.4　绝缘终测≥10 MΩ;分离开关终态=断电。

A12.5　全部记录并入质量数据包,提交 FQC 放行。

质量控制:全项 QT-001 §4 表。

# 3 缺陷与不合格品处理

- 尺寸超差:孔位/平面度超差件一律隔离评审,禁止现场修配(氧化后禁止机加);报废补投。
- 氧化膜破损:局部≤2 mm² 可用导电涂层修补并记录;大面积→返氧化(整件)。
- 滑丝/乱扣:更换被连接件或镶嵌钢丝螺套(需评审)。
- 太阳片隐裂:零接受,报废换片。
- 胶接失败:清除残胶(禁刮伤氧化膜)重新胶接,固化时间加倍验证。
- 全部不合格品填写 NCR 单,归档质量数据包。

PANO-3U-WI-001 装配工艺规程 v1.0

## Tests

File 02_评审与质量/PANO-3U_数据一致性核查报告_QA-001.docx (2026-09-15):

PANO-3U 双鱼眼全景立方星

(3U CubeSat · 500km SSO 全景成像任务)

数据一致性与制造性核查报告

全部原始交付物交叉核对 · 投产放行条件核查

文档编号 | PANO-3U-QA-001
版本 | v1.0
编制日期 | 2026-09
编制 / 审核 / 批准 | / /
分发 | 制造 / 质量 / 采购 / 试验

# 1 目的与方法

在投产放行前,对 PANO-3U 全部原始交付物进行跨文件数据一致性核查与制造性检查,识别阻断生产的不一致项并给出处理决定。方法:(1)脚本化解析 13 个 DXF 加工文件,逐孔与《详细设计说明书》孔位坐标表比对;(2)脚本化检索 KiCad 原理图、固件源码、地面站代码中的关键器件型号与参数;(3)人工比对 BOM 数量与几何装配关系核算;(4)质量、链路、能源等指标在说明书/结构报告/仿真报告三处交叉验证。核查脚本与中间结果(xcheck_result.txt 等)随本包归档。

# 2 核查范围

文件 | 版本 | 核查内容
详细设计说明书 | vC | 尺寸/孔位/紧固件/堆栈/热修订
电子系统设计规格书 | vB | 器件型号/总线/速率
DXF 加工文件 | ×13 (v4) | 轮廓/孔位坐标/孔径(全量解析)
全级 BOM 清单 | v1 xlsx | 数量/规格(4 表全量)
KiCad 工程(4 板) | vB | 器件型号 grep(TPS2557/2553 等)
OBC 固件源码(20 文件) | vB | 关键参数 grep(DEPLOY/heat/9600 等)
地面站源码 | vB | receiver.py R1 修复验证
设计评审报告 / 结构校核 / 仿真报告 | v1/vB/v1 | 结论与数据交叉验证
图纸 v4 PDF(18+3 页) | v4 | 目录与关键尺寸抽样

# 3 已验证一致项(放行依据)

编号 | 核查项 | 结果
D1 | DXF 13 个与说明书 §2.2-2.3 孔位坐标表:端板 H1-H4(±45.75)/H5-H12/H13-H16(±38)/C1(60×30 R4)/S1-S3/R1;侧板 K1-K10(30/90/170/250/310 × 6/77)/相机窗(170,41.5)Ø26+4×M2/过线孔 Ø6;隔板八角外形+56×56+4×Ø3.2;导轨 7 攻丝位;MEC-111 Ø22+4×Ø2.2;PLD-201 4×Ø2.7;压线卡/天线座/开关支架/电池支架展开料 — 全部一致 | ✓ 通过
D2 | TPS2557 已入 EPS 原理图(eps.kicad_sch 中出现,评审 E4 关闭属实) | ✓ 通过
D3 | receiver.py KISS 修复 frame[16:] 存在;frame[16:-2] 仅在 AX.25(含 FCS)分支,逻辑正确(评审 R1 关闭属实) | ✓ 通过
D4 | 发射质量 2.83 kg:说明书 = 结构校核 v4 补遗 = 仿真 S0(2359 g + 20%)三处一致 | ✓ 通过
D5 | 紧固件几何核算:F2=40(4 面×2 轨×5 点)、F9=8、F13=8、F7=8、F8=8、F14=8、分离开关 3、太阳片 72(+备 6)、SS34×8(每串 2 只)与装配关系一致 | ✓ 通过
D6 | 能源/链路定值:72 片 18.4 W BOL、日发电 81.9 Wh vs 日耗 30 Wh(2.7×);57.6 kbps 裕量 10.7 dB — 说明书与仿真一致 | ✓ 通过
D7 | 热修订三要素(电池 MLI、加热 3 W、LT3652 NTC 0°C 禁充)在说明书 §5 与仿真 S3 一致 | ✓ 通过
D8 | 评审阻断项 E1/E2/E3 关闭证据齐全:相机 ±X 侧装(DXF 103A/111)、开关 NC(BOM E21)、PCB/隔板 45° 切口(MEC-105 DXF) | ✓ 通过

# 4 发现问题与处理决定

## 4.1 A 类:阻断生产(必须修正后投产)

编号 | 问题与证据 | 影响 | 处理决定 | 责任文件
A1 | F5 双通铜柱 M3×12 单机数量 8 根。几何核算:堆栈 E9→F5→E8→F5→MEC-105→F5→E7 共 3 道层距,每道 4 根(安装孔 4×Ø3.2/76×76 贯通)= 12 根;F4 M3×15 一道层距仅需 4 根而 BOM 8 根 | 缺料停工(F5 缺 4 根);F4 冗余掩盖问题 | BOM v2:F5=12(采购 16 含备),F4=4(采购 8 含备);说明书 §2.5 同步修订 | BOM、说明书 §2.5
A2 | BOM E17 电池加热膜 5V/2W;仿真 S3 冷工况修订与说明书 §5 均已要求 3 W(2 W 时电池 −21°C,违反 0°C 充电禁限) | 按旧 BOM 采购将装 2 W 加热膜,冷工况不达标 | BOM v2:E17 改 5V/3W 40×40 ×2 | BOM
A3 | 电池包 MLI 多层隔热组件为冷工况修订必需件,说明书 §5 与仿真 S3 均提及,BOM 无此项 | 漏采购→冷工况不达标 | BOM v2:新增 E34 MLI 组件(双面镀铝聚酯膜 10 层,外协包覆)×2 | BOM

## 4.2 B 类:文档不同步(投产前更新文档,不阻断采购)

编号 | 问题与证据 | 处理决定
B1 | KiCad README 写"TPS2553×4 电子保险丝";原理图实际 U20=TPS2557、U21-23=TPS2553 | 更新 README 文案;投板 BOM 以原理图网表为准
B2 | 数传默认速率:说明书 §1.1/仿真 S6 定值 57.6 kbps(裕量 10.7 dB);电子规格书 §3 与固件 comm.c 仍为 9.6 kbps(9600) | 规格书更新;固件速率改 57600 为默认(阶段 A 联调配置项)
B3 | 评审 R6 称固件已有 DEPLOY_DELAY_S 参数 — 源码 grep 无此常量(deploy 延时逻辑存在但命名不同);J1 信号名 WD_KICK/HEAT_EN 与固件内部命名未对齐 | C6 软件在环联调时统一信号名与参数名,并回写规格书

## 4.3 C 类:第三方/试验收口项(源自评审第四节,纳入 MFG-001 §7)

FEA 复核、镜头实物验证、辐照摸底、热真空、EMC/频率许可、软件在环联调共 6 项,非文件不一致,为投产并行启动、飞行件放行前置的开放项,详见 MFG-001 §7 表。

## 4.4 说明:质量历史数据差异

结构校核报告早期版本按 BOM 估算质量 1.73/2.2 kg,与几何重建 2.36/2.83 kg 不一致 — 该差异已由 v4 补遗正式勘误(载荷线性放大后 SF≥28 结论不变),三文件现均以 2.83 kg 为准,不构成放行障碍。设计文件引用质量时统一使用 2.83 kg。

# 5 结论与放行意见

核查结论:全套文件几何与电气主线数据一致性好,DXF 可直接投产;存在 3 项 BOM 级阻断问题(A1-A3),已在本包《修正版 BOM v2》中修正;3 项文档不同步(B1-B3)已给出处理决定。放行意见:(1)按修正版 BOM v2 与 DXF v4 投产结构件与 PCB(阶段 A);(2)B1-B3 文档修订与 C 类开放项并行启动;(3)飞行件放行严格执行 MFG-001 §7 七项条件。

PANO-3U-QA-001 数据一致性与制造性核查报告 v1.0

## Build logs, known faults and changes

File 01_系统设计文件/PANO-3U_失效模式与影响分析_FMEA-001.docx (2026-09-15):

PANO-3U 双鱼眼全景立方星

(3U CubeSat · 500km SSO 全景成像任务)

失效模式与影响分析(FMEA)

严酷度/发生度/检测度评分 · RPN 排序 · 补偿措施

文档编号 | PANO-3U-FMEA-001
版本 | A(整星功能级)
编制日期 | 2026-09
编制 / 审核 / 批准 | / /
分发 | 制造 / 质量 / 采购 / 试验

评分:严酷度 S 与发生度 O 各 1-5(5 最严重/最频),检测度 D 1-5(5 难检测);RPN=S×O×D,≥36 列为重点管控。覆盖整星功能级单点失效;详细件级 FMEA 在阶段 B 补充。

编号 | 失效模式 | 影响 | S | O | D | RPN | 补偿措施
FM-01 | 电池热失控 | 整星损毁 | 5 | 2 | 2 | 20 | BMS+点焊工艺+防爆袋+TVAC;MLI 内通风设计
FM-02 | 单节 18650 开路/容量衰减 | 电源能力降 50% | 4 | 2 | 2 | 16 | 原厂正品+内阻配对;SOC 遥测;2S2P 拓扑单节失效仍可部分供电
FM-03 | 太阳串开路(互连条断裂) | 该面发电归零(−25%) | 4 | 2 | 2 | 16 | 焊接工艺 KCP-4;旁路二极管 SS34 隔离故障串
FM-04 | MPPT 通道失效 | 该面充电失效 | 3 | 2 | 2 | 12 | 四通道独立,失效面由旁路二极管隔离;其余三面 75% 仍闭环
FM-05 | 5V/3.3V 母线失效 | 整星失功能 | 5 | 1 | 3 | 15 | TPS54331 航空级降额;输入 TVS;上电时序测试
FM-06 | OBC 程序跑飞/单粒子翻转 | 功能中断至复位 | 3 | 3 | 2 | 18 | TPS3823 看门狗 30s;W25Q128 参数双备份;SAFE 自动恢复
FM-07 | B-dot 消旋失效 | 角速率不衰减,成像模糊 | 3 | 2 | 2 | 12 | 三轴冗余磁矩;DRV8837 独立;地面可上载新参数
FM-08 | 磁力矩器单轴开路 | 该轴消旋失效 | 3 | 2 | 2 | 12 | 三轴正交,单轴失效其余两轴可控(姿态动力学验证)
FM-09 | UHF PA 失效 | 数传中断(指令不可达) | 4 | 2 | 3 | 24 | PA 供电限流保护;遥测监测电流;备份:信标低功率模式
FM-10 | 天线未展开(热刀失效) | 链路−30 dB,应急仅低码率 | 4 | 2 | 2 | 16 | 双刀冗余+多次重试;ANT_STAT 遥测;卷收态仍有近距通信可能
FM-11 | 相机离焦/污染 | 成像质量劣化 | 3 | 2 | 2 | 12 | 锁焦点胶工艺(KCP-3);IR-cut/镜盖保护;在轨重调焦不可行→地面验收严格
FM-12 | SD 卡损坏/写满 | 数据丢失 | 3 | 2 | 2 | 12 | 工业级宽温卡;断电保护文件系统;空间回收;eMMC 备份参数
FM-13 | 分离开关粘滞(常通) | 舱内带电风险(拒载) | 5 | 1 | 1 | 5 | NC 接法+行程实测(A9 停检点);P-POD 插入检验由发射场执行
FM-14 | RBF 未拔即发射 | 整星不上电(任务失败) | 5 | 1 | 1 | 5 | 发射场流程检查单(CDS 标准程序);RBF 拔出状态可视
FM-15 | 热超限(电池<0°C 充电) | 电池永久损伤 | 4 | 2 | 2 | 16 | MLI+3W 加热+NTC 禁充+TVAC 实测(C4);SAFE 保持加热
FM-16 | 结构紧固松动(振动) | 单点结构失效 | 4 | 1 | 2 | 8 | 力矩+243+marking;振动后 100% 复查(KCP-5)
FM-17 | CAM1 带宽不足 | 视频指标降级 | 3 | 3 | 1 | 9 | 指标已调 2.8K30;备选 CM5/USB3(C6 实测)

结论:无 RPN≥36 的不可接受项;最高 FM-09(24)与 FM-02/03/10/15(16)均有补偿措施;整星设计遵循"故障-安全"原则:任一单点失效不导致永久性硬件损坏,可通过地面指令或复位恢复;电池与分离安全链以工艺停检点管控。

PANO-3U-FMEA-001 失效模式与影响分析(FMEA) A(整星功能级)

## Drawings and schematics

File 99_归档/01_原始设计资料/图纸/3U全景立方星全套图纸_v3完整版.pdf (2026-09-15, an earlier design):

(+Z )

(-Z )

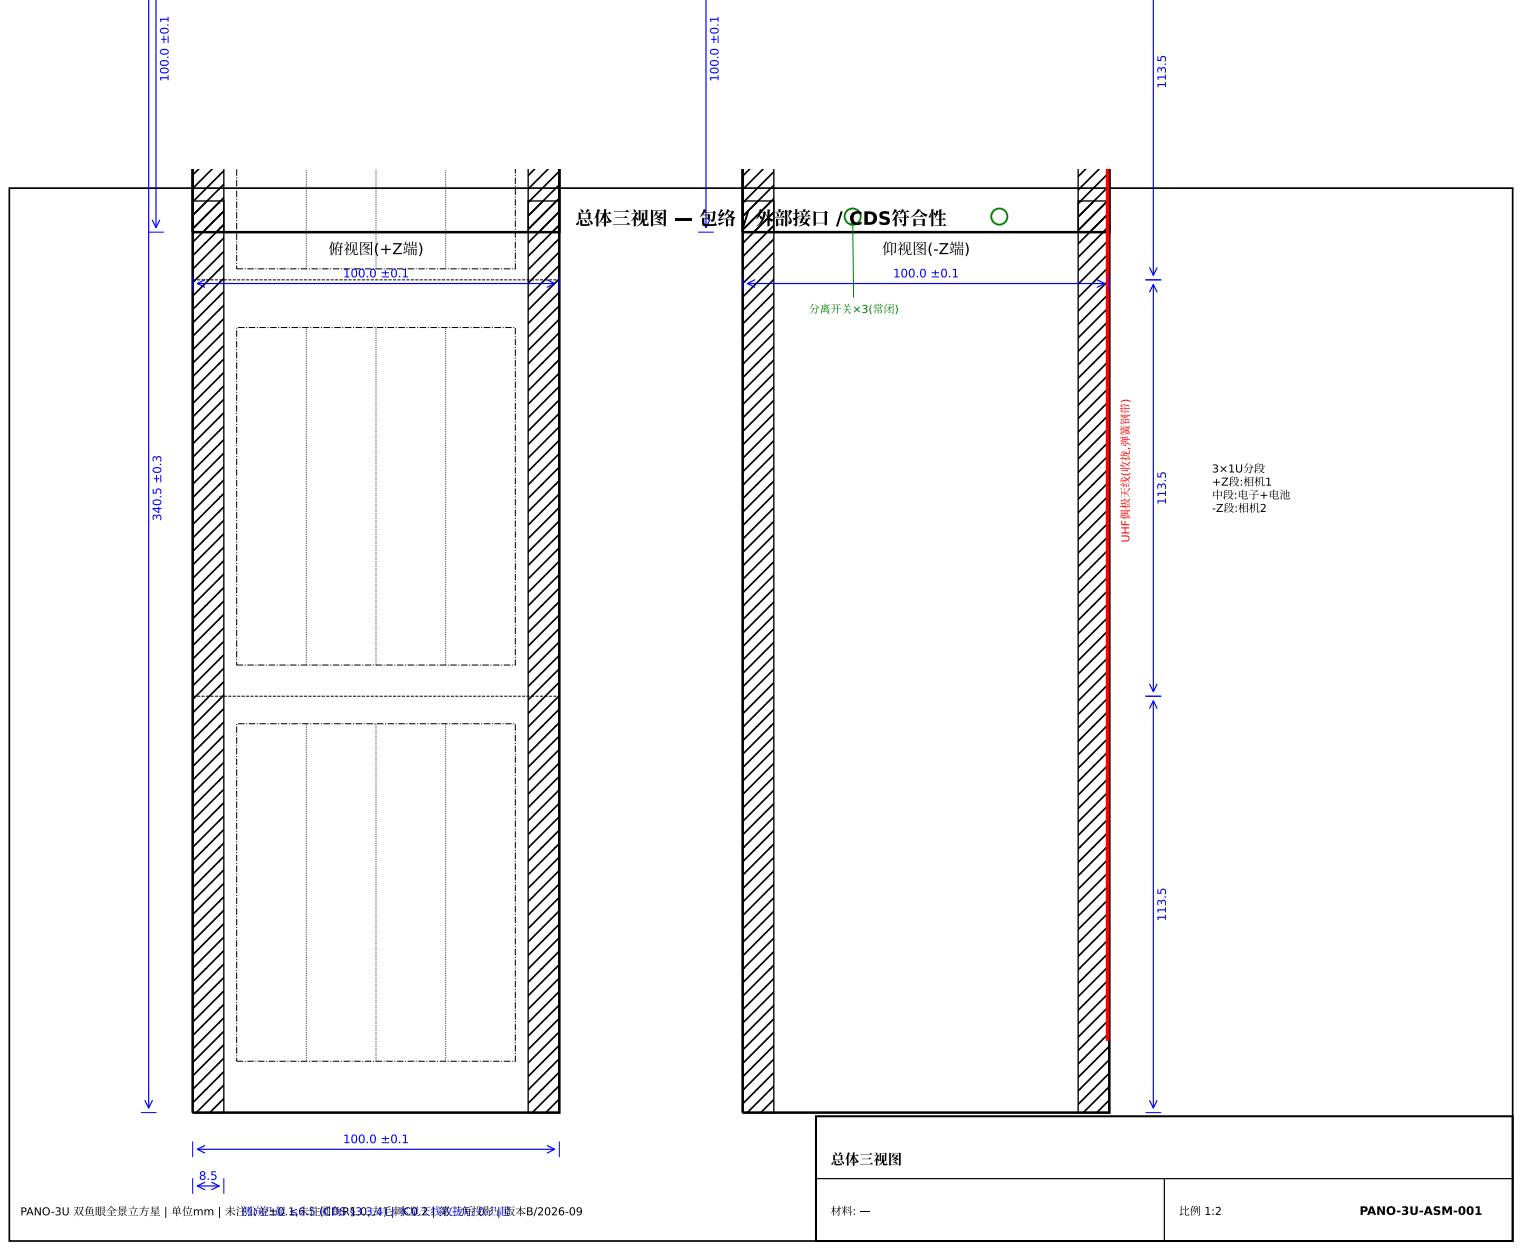
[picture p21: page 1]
6.5 (CDS §3.3.4) |; UHF ( , ); / CDS; PANO-3U; PANO-3U-ASM-001

( Z , | = | )
(ESD , | , | )

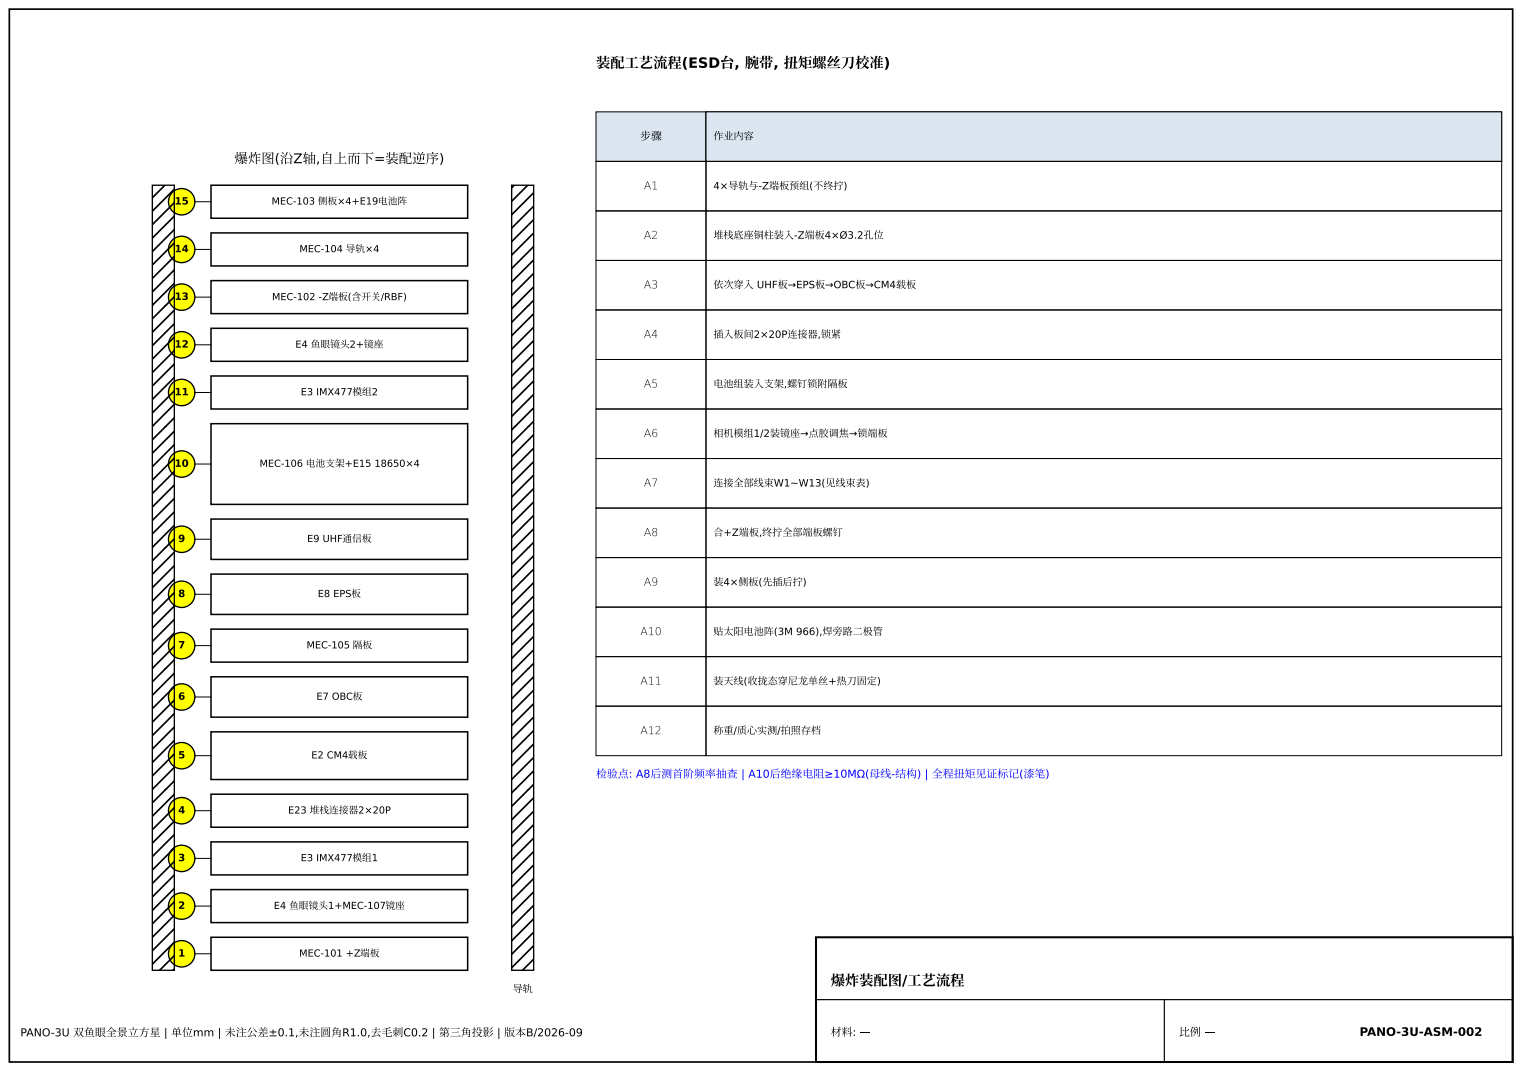
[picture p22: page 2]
1 MEC-101 +Z; 1+MEC-107; E3 IMX477; 6 E7 OBC; 7 MEC-105; 8 E8 EPS; 9 E9 UHF; MEC-106; MEC-102 -Z; /RBF); MEC-104; MEC-103; PANO-3U; PANO-3U-ASM-002

A3 | UHF EPS OBC CM4

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

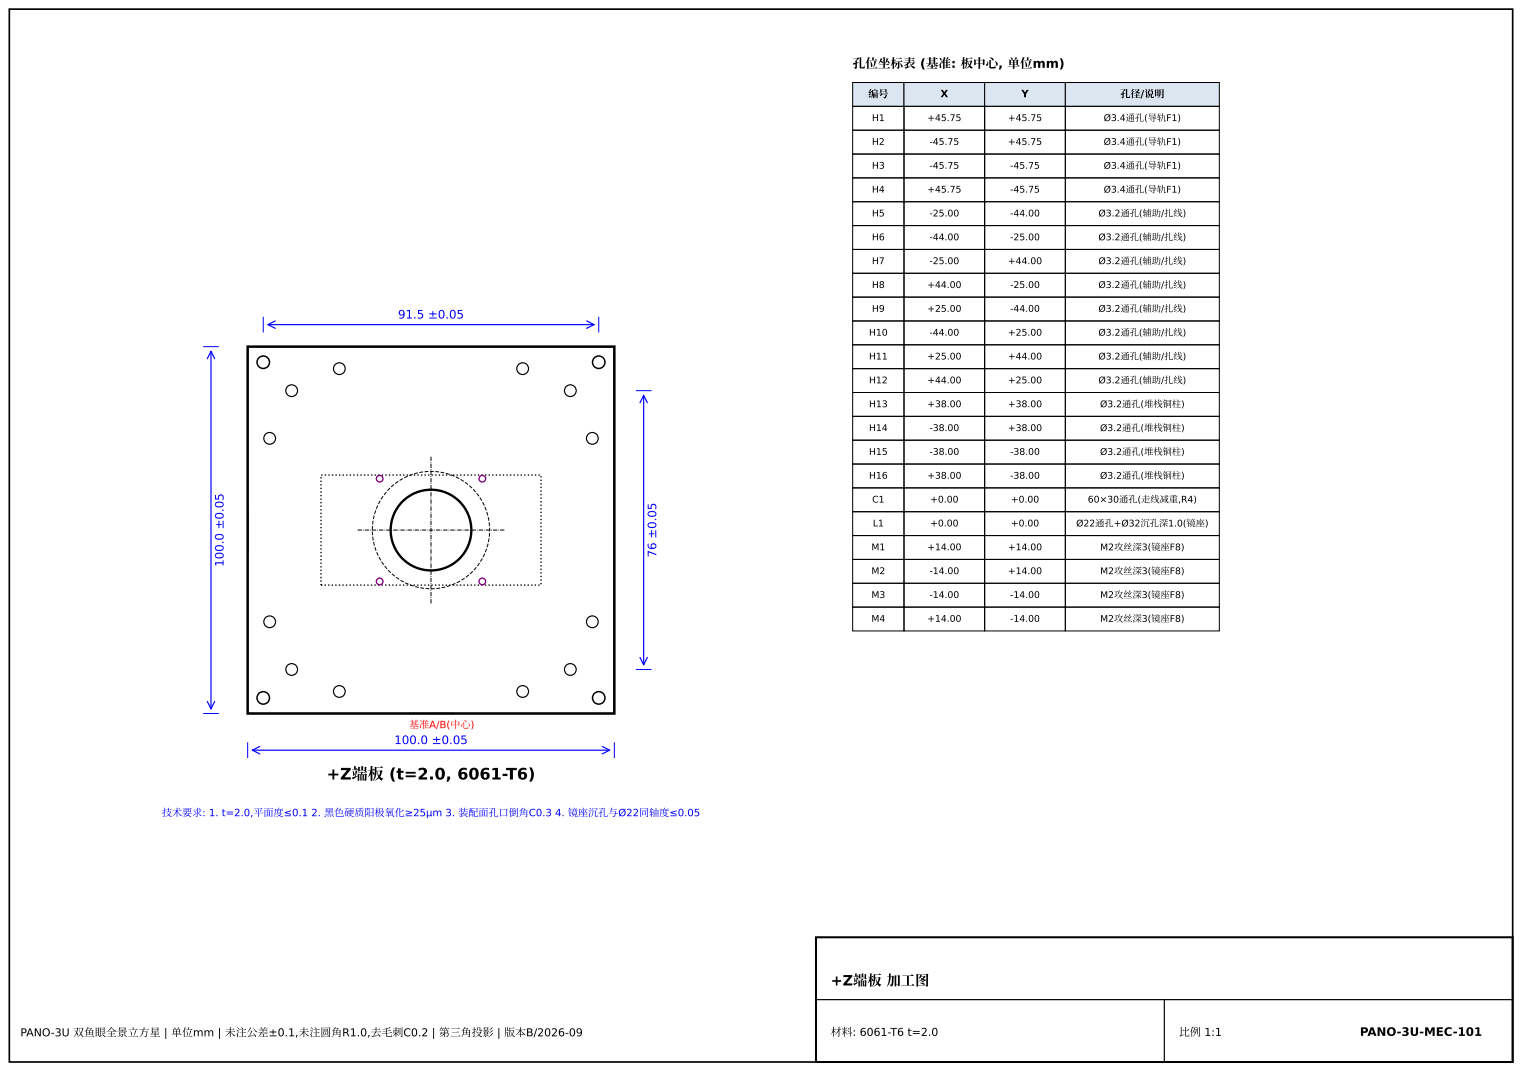
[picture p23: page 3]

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

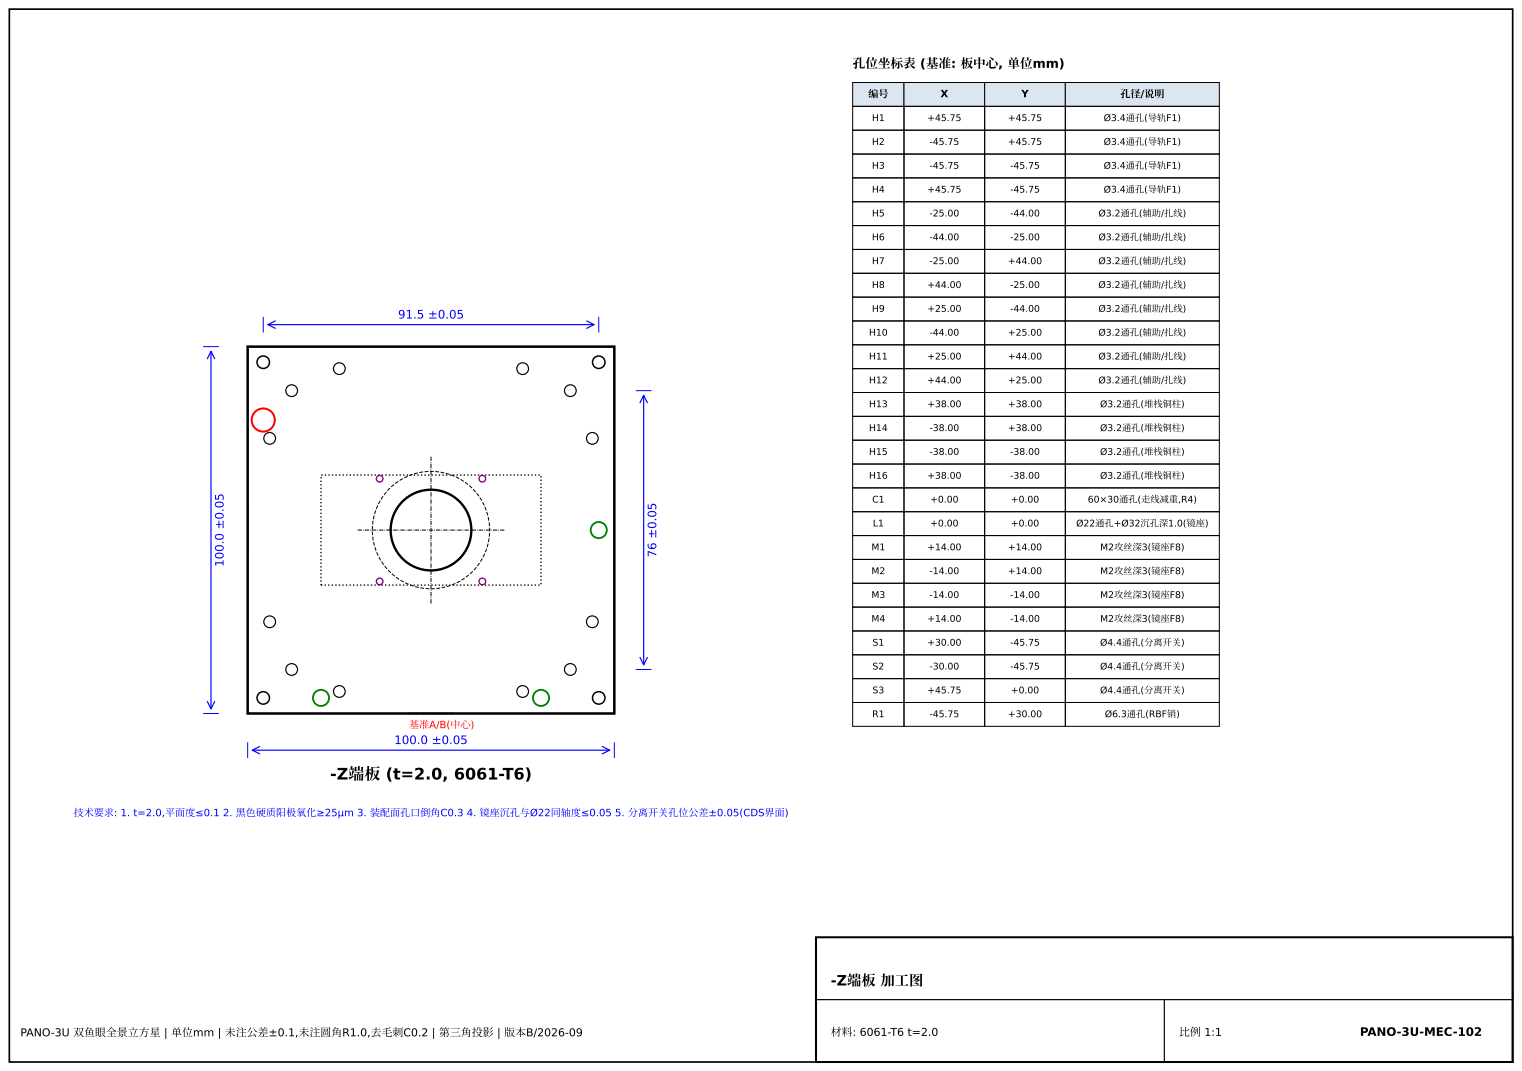
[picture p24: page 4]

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

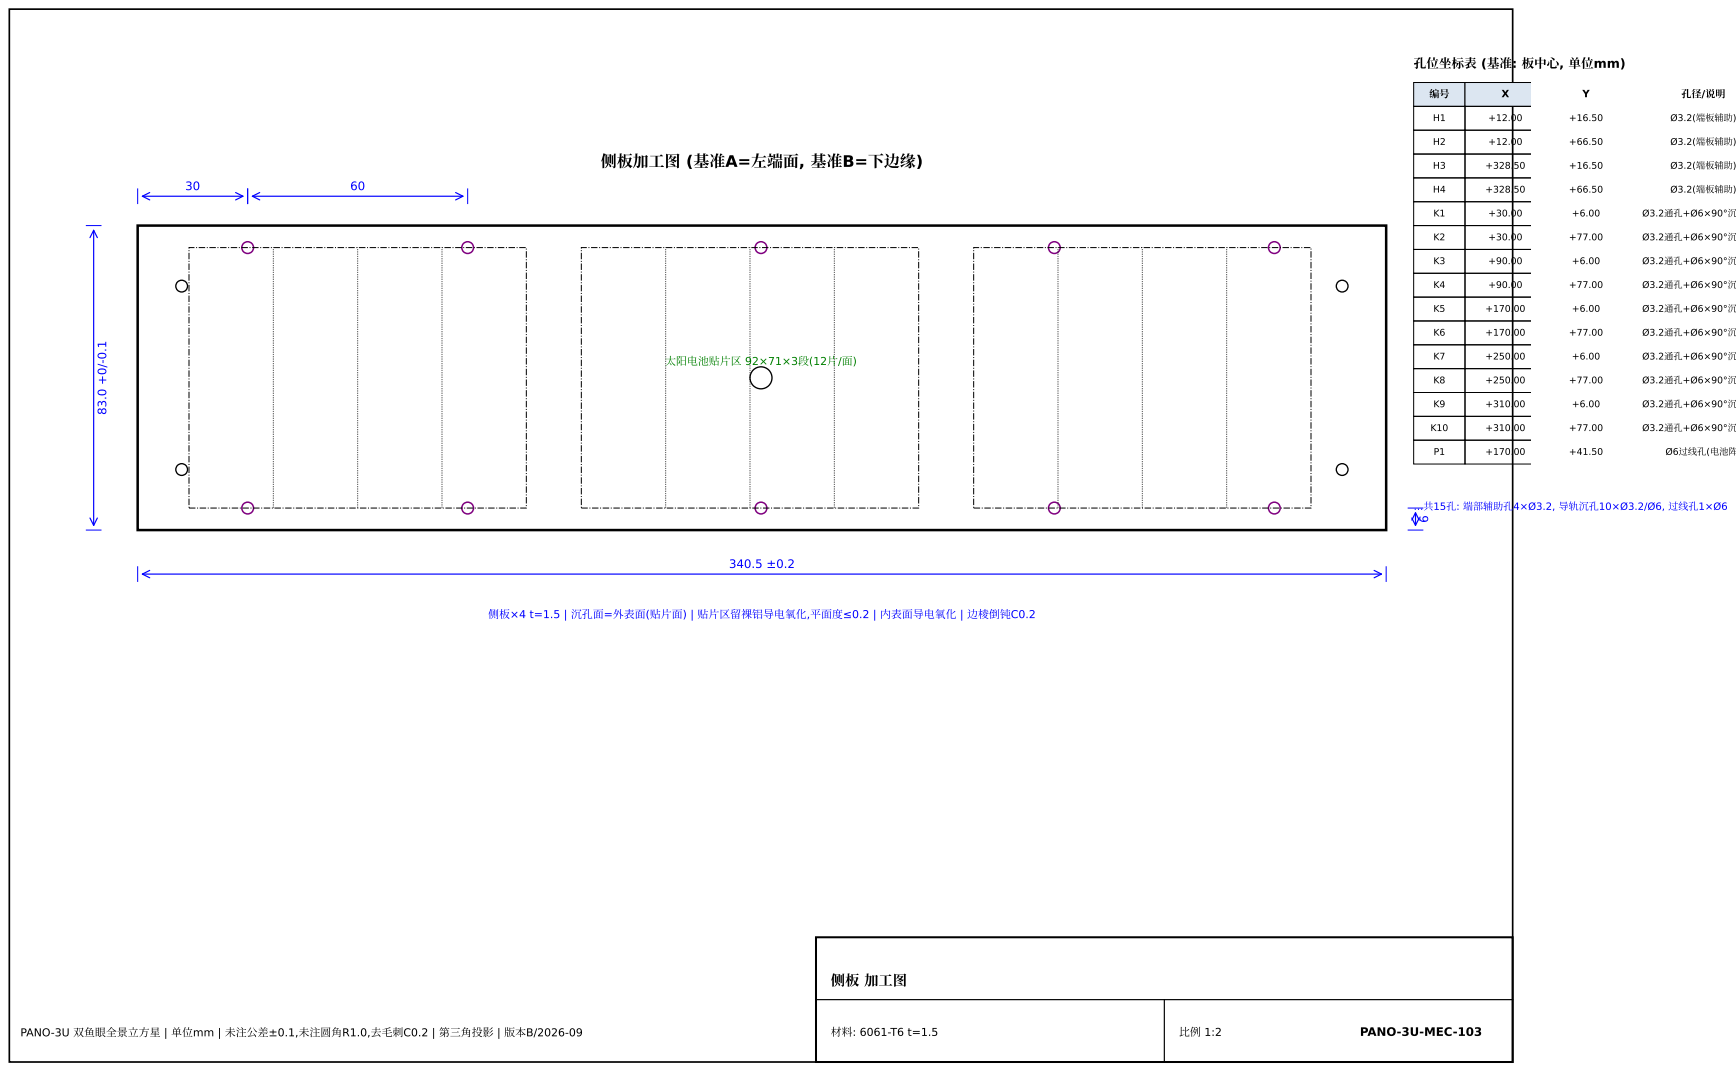
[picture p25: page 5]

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

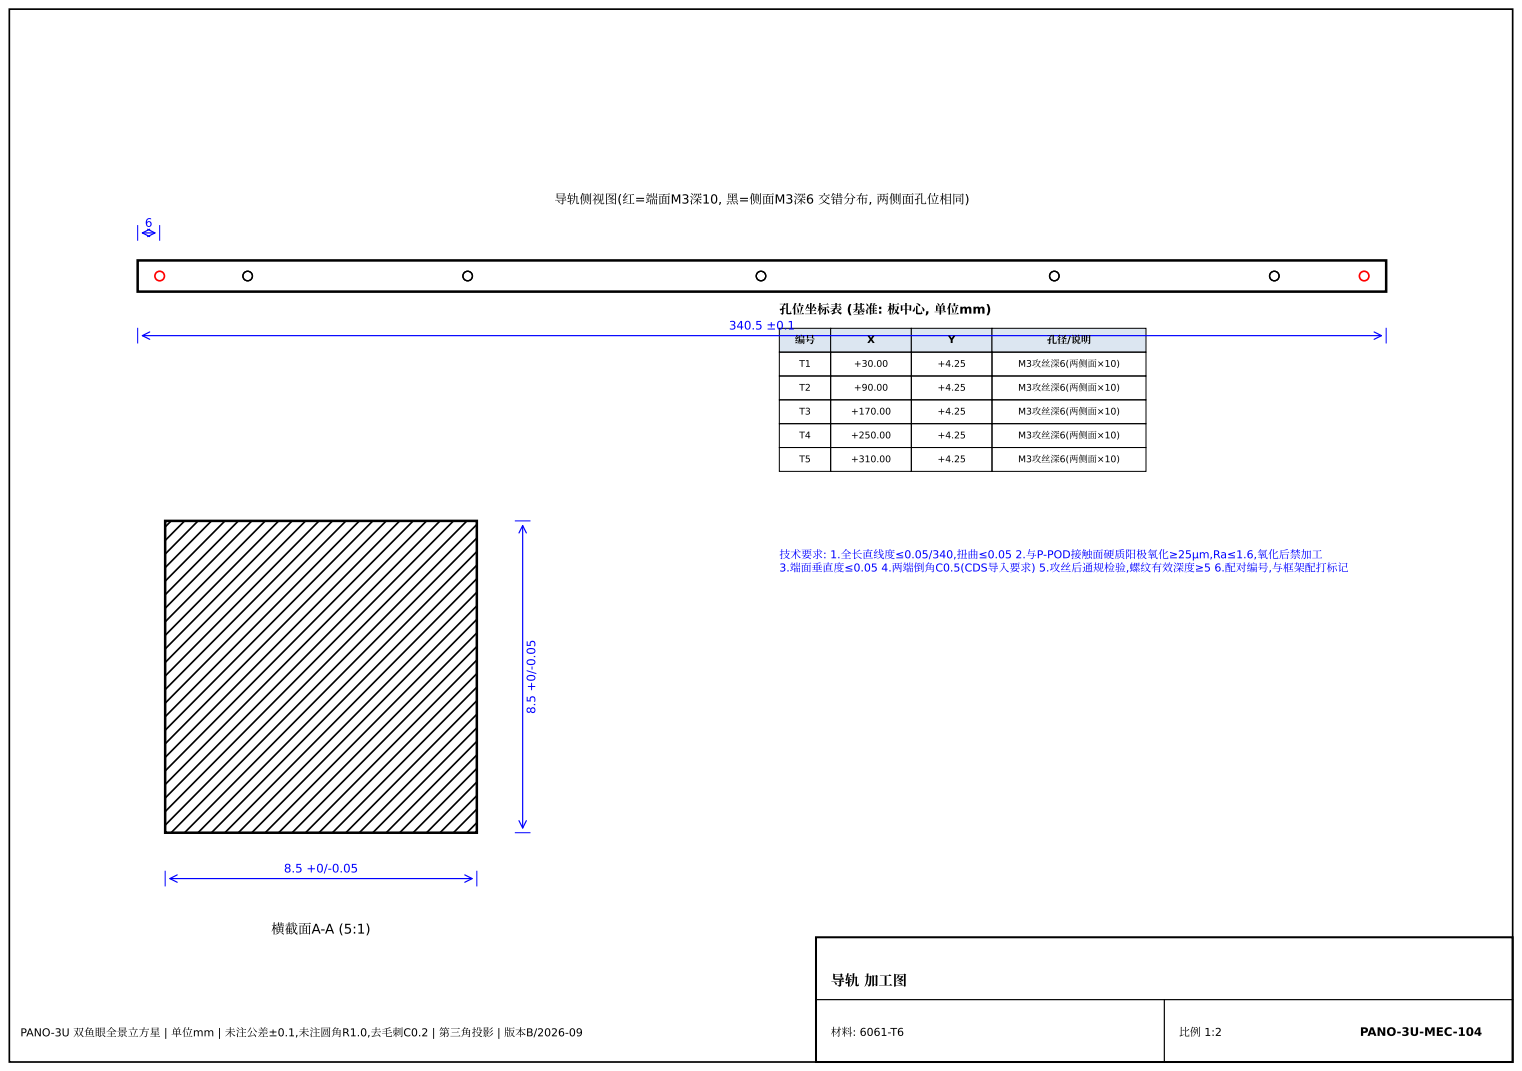
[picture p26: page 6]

( | : | , | mm)
| X | Y | /

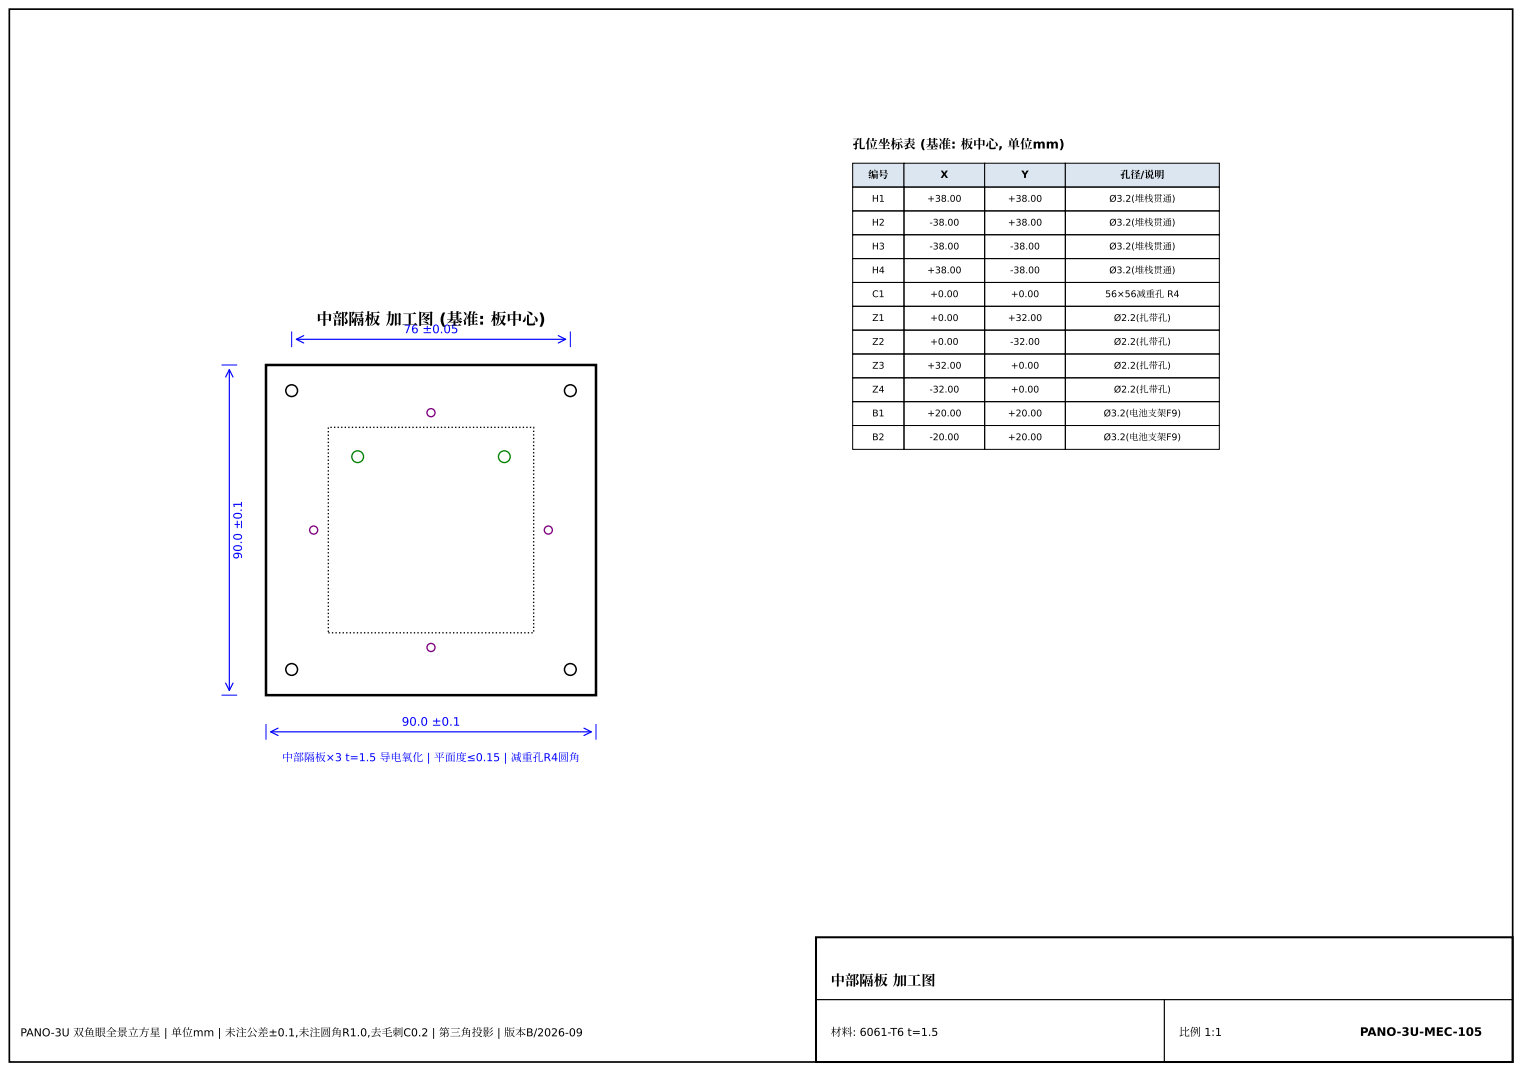
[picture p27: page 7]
PANO-3U; PANO-3U-MEC-105

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

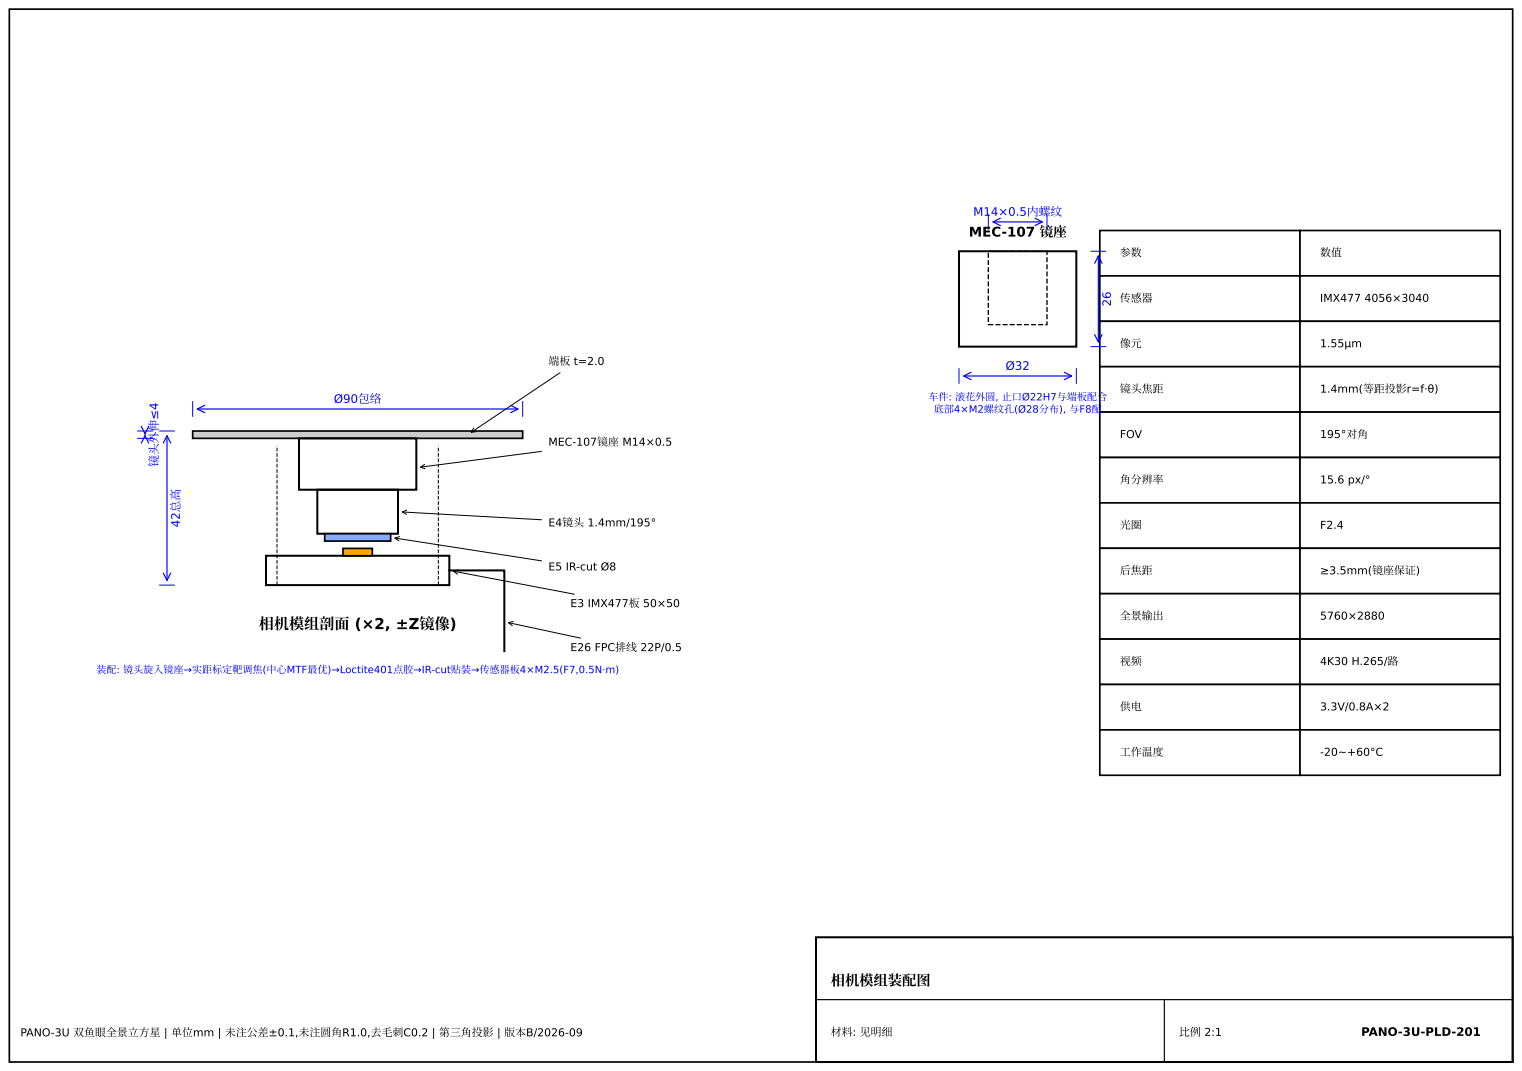
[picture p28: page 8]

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

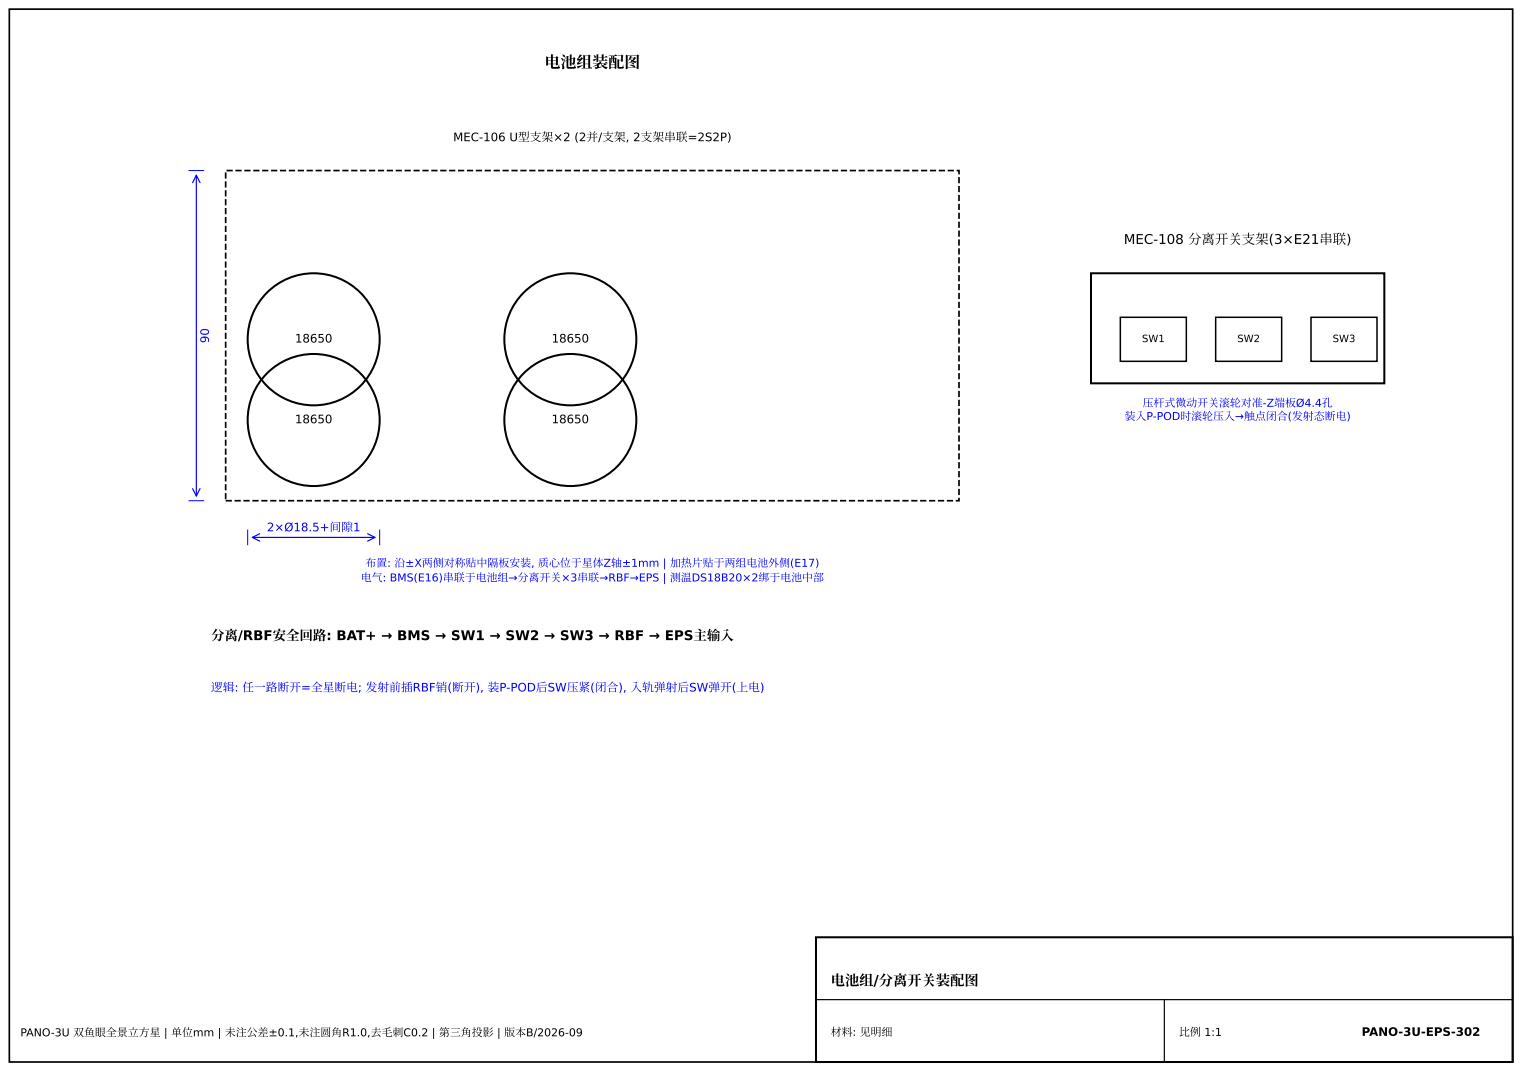
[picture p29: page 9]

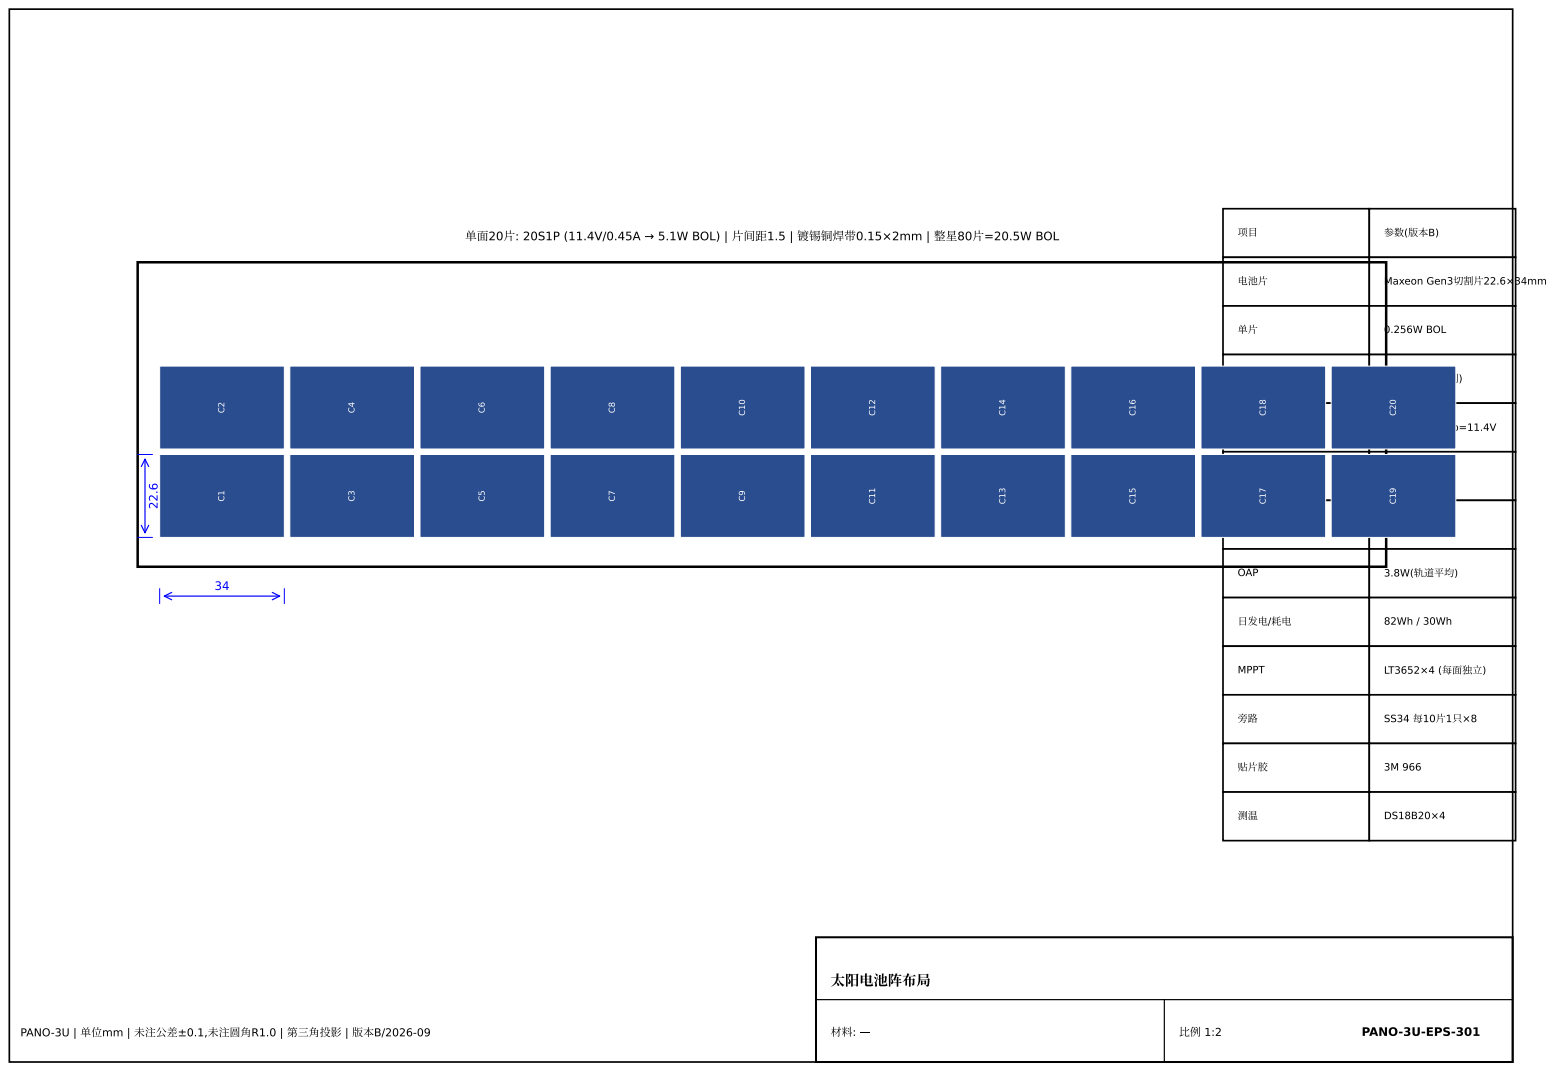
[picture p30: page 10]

20S1P/ , Vmp=11.4V

BOL | | 20.5W

MPPT | LT3652×4 ( )

( | PTFE | M22759 , | 22AWG/ | 28AWG, | 20mm)
| | | / | / | mm

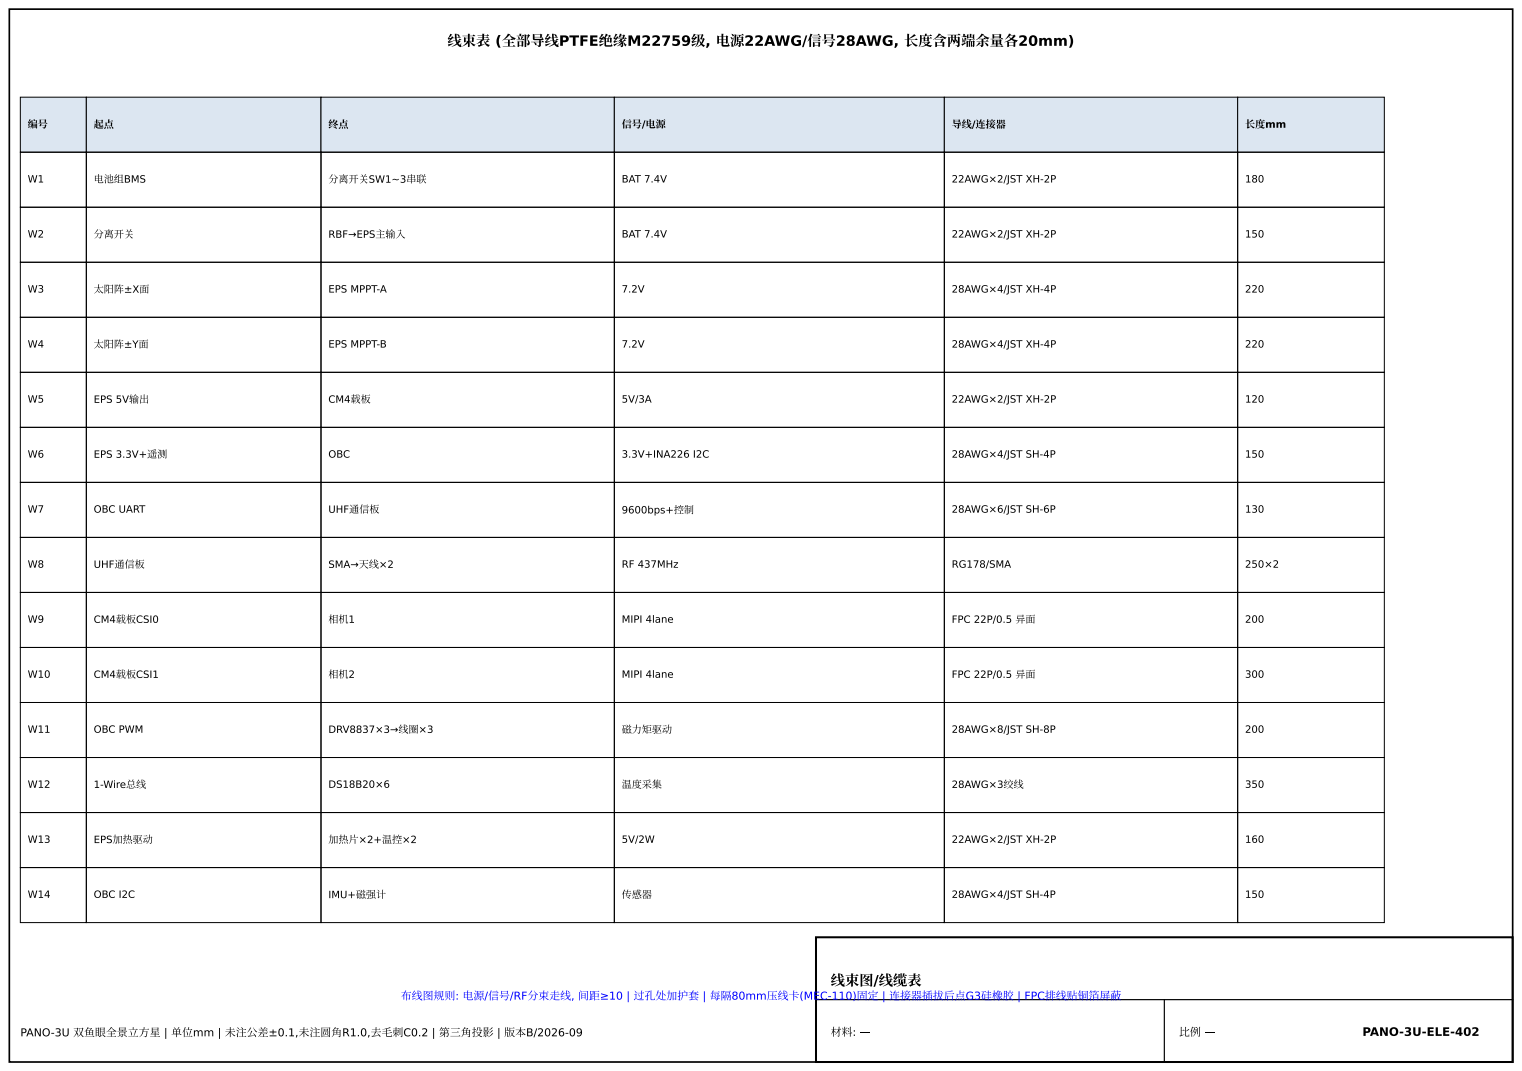
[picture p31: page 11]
(MEC-110); | FPC; PANO-3U; PANO-3U-ELE-402

W1 | BMS | SW1~3 | BAT 7.4V | 22AWG×2/JST XH-2P | 180

W2 | | RBF EPS | BAT 7.4V | 22AWG×2/JST XH-2P | 150

W3 | ±X | EPS MPPT-A | 7.2V | 28AWG×4/JST XH-4P | 220

W4 | ±Y | EPS MPPT-B | 7.2V | 28AWG×4/JST XH-4P | 220

W5 | EPS 5V | CM4 | 5V/3A | 22AWG×2/JST XH-2P | 120

W6 | EPS 3.3V+ | OBC | 3.3V+INA226 I2C | 28AWG×4/JST SH-4P | 150

W7 | OBC UART | UHF | 9600bps+ | 28AWG×6/JST SH-6P | 130

W8 | UHF | SMA ×2 | RF 437MHz | RG178/SMA | 250×2

W9 | CM4 CSI0 | 1 | MIPI 4lane | FPC 22P/0.5 | 200

W10 | CM4 CSI1 | 2 | MIPI 4lane | FPC 22P/0.5 | 300

W11 | OBC PWM | DRV8837×3 ×3 | | 28AWG×8/JST SH-8P | 200

W12 | 1-Wire | DS18B20×6 | | 28AWG×3 | 350

W13 | EPS | ×2+ ×2 | 5V/2W | 22AWG×2/JST XH-2P | 160

W14 | OBC I2C | IMU+ | | 28AWG×4/JST SH-4P | 150

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

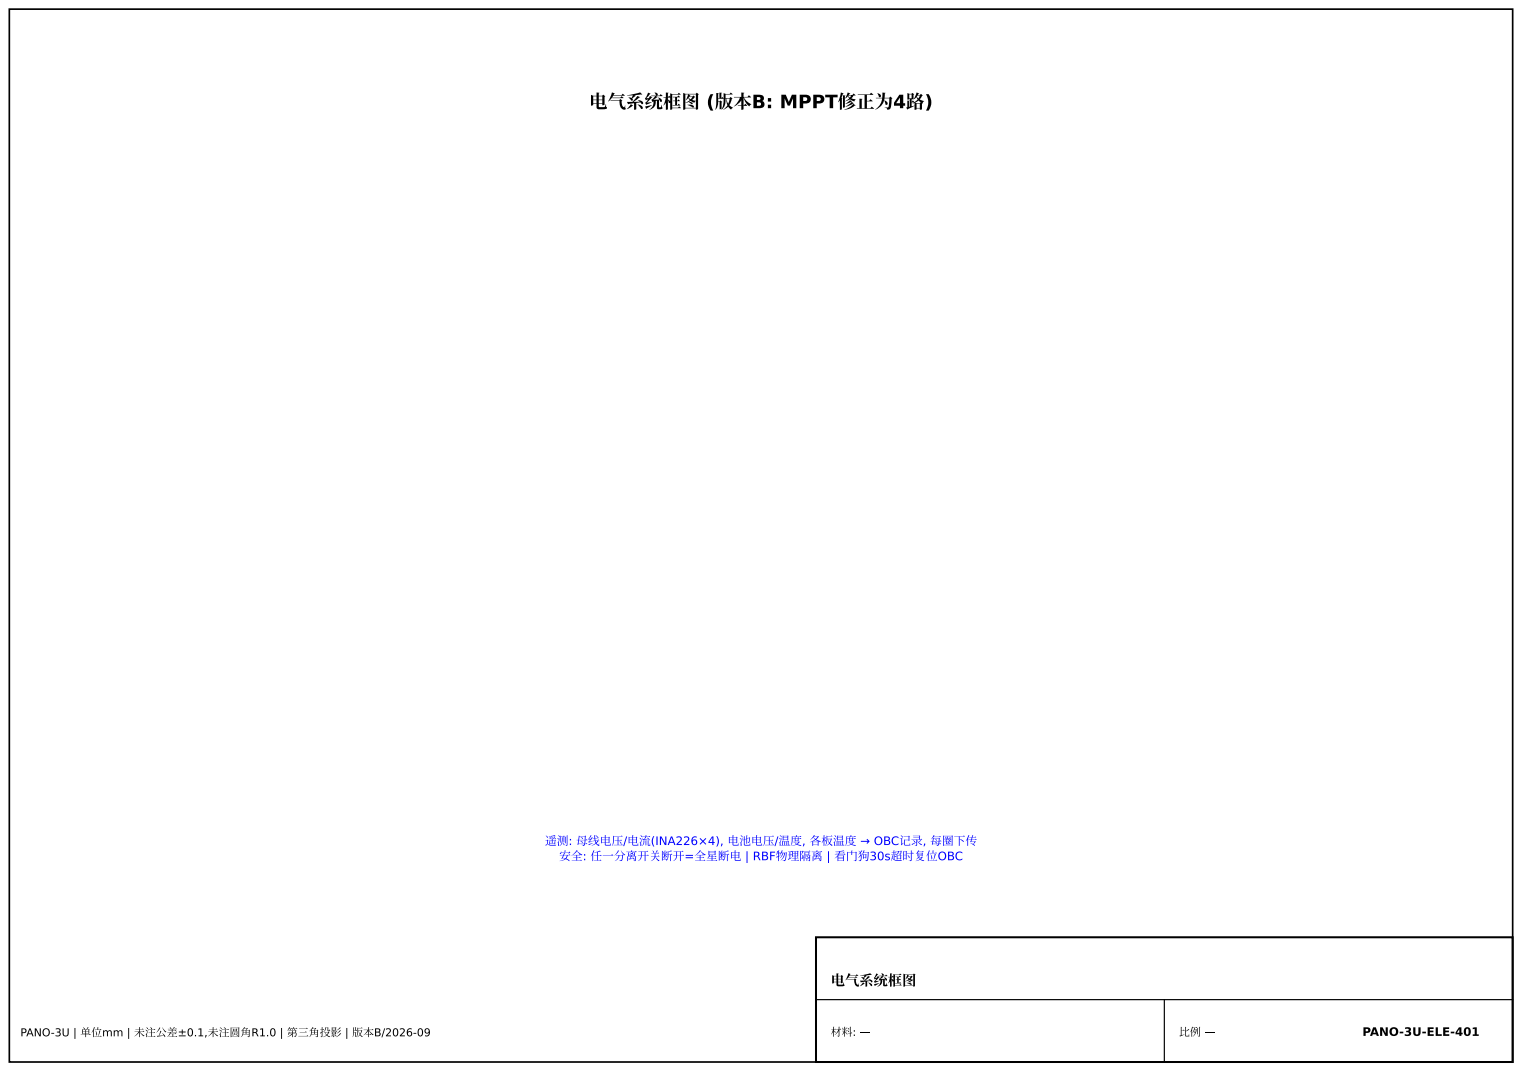
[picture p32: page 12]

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

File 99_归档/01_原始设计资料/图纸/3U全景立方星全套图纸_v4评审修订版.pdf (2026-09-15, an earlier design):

±X | (v4 | )

z=170

PANO-3U; Ø26 +4×M2(MEC-103A); ( +Z) CDS; CDS 6.5

v4: | ±X
( | EPS | OBC CM4 )

PANO-3U; EPS; OBC; 1: MEC-111 +MEC-107 +; (NC)+RBF+; OBC CM4 , 2×20P; ±X, FPC CM4

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


( | : | , | mm)
| X | Y | /

PANO-3U; PANO-3U-MEC-105

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



20S1P/ , Vmp=11.4V

BOL | | 20.5W

MPPT | LT3652×4 ( )

( | PTFE | M22759 , | 22AWG/ | 28AWG, | 20mm)
| | | / | / | mm

(MEC-110); | FPC; PANO-3U; PANO-3U-ELE-402

W1 | BMS | SW1~3 | BAT 7.4V | 22AWG×2/JST XH-2P | 180

W2 | | RBF EPS | BAT 7.4V | 22AWG×2/JST XH-2P | 150

W3 | ±X | EPS MPPT-A | 7.2V | 28AWG×4/JST XH-4P | 220

W4 | ±Y | EPS MPPT-B | 7.2V | 28AWG×4/JST XH-4P | 220

W5 | EPS 5V | CM4 | 5V/3A | 22AWG×2/JST XH-2P | 120

W6 | EPS 3.3V+ | OBC | 3.3V+INA226 I2C | 28AWG×4/JST SH-4P | 150

W7 | OBC UART | UHF | 9600bps+ | 28AWG×6/JST SH-6P | 130

W8 | UHF | SMA ×2 | RF 437MHz | RG178/SMA | 250×2

W9 | CM4 CSI0 | 1 | MIPI 4lane | FPC 22P/0.5 | 200

W10 | CM4 CSI1 | 2 | MIPI 4lane | FPC 22P/0.5 | 300

W11 | OBC PWM | DRV8837×3 ×3 | | 28AWG×8/JST SH-8P | 200

W12 | 1-Wire | DS18B20×6 | | 28AWG×3 | 350

W13 | EPS | ×2+ ×2 | 5V/2W | 22AWG×2/JST XH-2P | 160

W14 | OBC I2C | IMU+ | | 28AWG×4/JST SH-4P | 150

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

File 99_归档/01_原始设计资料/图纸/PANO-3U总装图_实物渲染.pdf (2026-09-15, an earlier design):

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

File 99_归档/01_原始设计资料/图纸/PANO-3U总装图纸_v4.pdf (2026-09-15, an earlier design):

, | GB/T 1804-m

PANO-3U; ASM-101; 5 EPS; OBC; CM⁴; MEC-103A; MEC-104; MEC-102; MEC-101; UHF; EPS; MEC-105; MEC-111/107; ×3+RBF; MEC-106; MEC-109; (0.4, 0.3,168.2) mm CDS Rev.14; CDS Rev.14 (

Z | ; Y | +Y

PANO-3U; MEC-104 ×4; MEC-102 (+MEC-108; , E21×3 NC, RBF); E8 EPS; MEC-105; E7 OBC; E15×4 + MEC-106×2 +; MEC-101; 1: MEC-111/107+E3+E4+E33; MEC-103A X; MEC-103A +X; MEC-103B +Y ( Y; E28+MEC-109 ×2; +3×E21(NC)+RBF; EPS; OBC CM4 (F5/F6; Loctite 243 (

6061-T6 | 3 | ASM-102 | 2026-09

§4.2


6061-T6 | 3 | ASM-103 | 2026-09

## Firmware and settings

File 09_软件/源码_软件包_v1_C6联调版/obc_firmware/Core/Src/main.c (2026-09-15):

/**
 * PANO-3U OBC 固件 - 主程序
 * MCU: STM32F405RGT6 @168MHz, HAL库
 * 任务: 遥测采集 / 模式管理 / 姿态控制(B-dot) / 载荷调度 / UHF通信
 * RTOS: FreeRTOS
 */
#include "main.h"
#include "obc_fsm.h"
#include "adcs.h"
#include "comm.h"
#include "eps_mon.h"
#include "payload_mgr.h"
#include "watchdog.h"
#include "log.h"

/* HAL 句柄 (CubeMX生成部分略, 此处声明) */
I2C_HandleTypeDef  hi2c1, hi2c2;
SPI_HandleTypeDef  hspi2;
UART_HandleTypeDef huart1;   /* 通信板 */
UART_HandleTypeDef huart2;   /* CM4载荷 */
TIM_HandleTypeDef  htim1;    /* PWM: 磁力矩器 XYZ */
WDT_Handle_t       hwdt;

/* 全局状态 */
SatState_t g_sat = {
    .mode = MODE_SAFE,
    .uptime_s = 0,
    .boot_count = 0,
    .last_error = ERR_NONE,
    .mag = {0}, .gyro = {0},
    .vbat_mv = 0, .ibat_ma = 0,
    .temp = {25,25,25,25,25,25},
};

/* FreeRTOS 任务 */
static TaskHandle_t h_task_hk, h_task_adcs, h_task_comm, h_task_pl;

void SystemClock_Config(void);  /* CubeMX生成: HSE 8M -> PLL -> 168M */

int main(void)
{
    HAL_Init();
    SystemClock_Config();

    /* 外设初始化 */
    MX_GPIO_Init();       /* 含分离开关/天线状态GPIO */
    MX_I2C1_Init();       /* INA226/IMU/磁强计 */
    MX_I2C2_Init();       /* DS3231 RTC */
    MX_SPI2_Init();       /* W25Q128 */
    MX_USART1_Init();     /* 通信板 9600 */
    MX_USART2_Init();     /* CM4 115200 */
    MX_TIM1_PWM_Init();   /* 磁力矩器驱动 */
    MX_ADC_Init();        /* 备份电压采集 */

    log_init();           /* W25Q128环形日志 */
    uint32_t boot = 0;
    log_get_bootcount(&boot);
    g_sat.boot_count = boot + 1;
    log_set_bootcount(g_sat.boot_count);
    log_event(EVT_BOOT, g_sat.boot_count);

    /* 入轨延时: CDS要求分离后30分钟才能发射RF/展开机构 */
    if (g_sat.boot_count <= 2) {   /* 仅入轨初期执行 */
        HAL_Delay(30U * 60U * 1000U);
        antenna_deploy();          /* 热刀释放天线 */
    }

    obc_fsm_init();
    adcs_init();
    comm_init();
    payload_mgr_init();

    /* 任务创建: 优先级 高->低 = 通信 > ADCS >  housekeeping > 载荷 */
    xTaskCreate(task_comm,    "comm", 1024, NULL, 4, &h_task_comm);
    xTaskCreate(task_adcs,    "adcs",  768, NULL, 3, &h_task_adcs);
    xTaskCreate(task_hk,      "hk",   1024, NULL, 2, &h_task_hk);
    xTaskCreate(task_payload, "pl",   1536, NULL, 1, &h_task_pl);

    vTaskStartScheduler();
    while (1);   /* 不应到达 */
}

/**
 * 内务任务: 1Hz 遥测采集 + 看门狗喂狗 + 电池保护
 */
void task_hk(void *arg)
{
    TickType_t last = xTaskGetTickCount();
    for (;;) {
        eps_mon_update();        /* INA226 x4 -> g_sat.vbat_mv 等 */
        adcs_read_sensors();     /* IMU + 磁强计 */
        thermal_update();        /* DS18B20 x6 -> 加热片控制 */
        power_guard();           /* 低压 -> SAFE模式 */

        wdt_kick();              /* 喂 TPS3823 (PA0翻转->实际是专用GPIO) */

        if ((g_sat.uptime_s % 30) == 0)
            comm_queue_beacon(); /* 30s信标 */

        g_sat.uptime_s++;
        vTaskDelayUntil(&last, pdMS_TO_TICKS(1000));
    }
}

/* 电池低压保护: VBAT<6.6V 进SAFE, 关载荷 */
void power_guard(void)
{
    if (g_sat.vbat_mv > 0 && g_sat.vbat_mv < 6600 && g_sat.mode != MODE_SAFE) {
        log_event(EVT_LOW_POWER, g_sat.vbat_mv);
        payload_power(false);    /* 断PAYLOAD_EN */
        heater_force(false);
        obc_set_mode(MODE_SAFE);
    }
}

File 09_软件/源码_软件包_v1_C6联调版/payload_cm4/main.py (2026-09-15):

"""PANO-3U 载荷主程序 (CM4)
状态机: BOOT -> IDLE -> (SHOOTING | RECORDING | TIMELAPSE) -> IDLE -> SHUTDOWN
运行: python3 main.py  (systemd服务 pano3u-payload.service)
"""
import os, time, threading, struct, signal, sys
from config import cfg
from camera import DualFisheyeCamera, ON_TARGET
from storage import StorageManager
from stitch import PanoStitcher
import link as L
import cv2
import numpy as np

MODE_IDLE, MODE_SHOOTING, MODE_RECORDING, MODE_TIMELAPSE = 0, 1, 2, 3


class PayloadApp:
    def __init__(self):
        self.mode = MODE_IDLE
        self.last_err = 0
        self.cam = DualFisheyeCamera(cfg)
        self.store = StorageManager(cfg)
        self.stitcher = None
        calib = os.path.join(os.path.dirname(__file__), cfg["calib_file"])
        if os.path.exists(calib):
            self.stitcher = PanoStitcher(calib, cfg["pano_width"], cfg["pano_height"])
        self.last_ping = time.time()
        self.video_deadline = None
        self.timelapse = None
        self._stop = False
        if ON_TARGET:
            self.link = L.UartLink(cfg["uart_port"], cfg["uart_baud"], self.on_cmd)
        else:
            self.link = None

    # ---------------- 指令处理 ----------------
    def on_cmd(self, cmd, pl):
        if cmd == L.CMD_PING:
            self.last_ping = time.time()
            self.link.send(L.RSP_ACK, bytes([cmd, 0]))
        elif cmd == L.CMD_TIME and len(pl) == 4:
            epoch = struct.unpack("<I", pl)[0]
            if ON_TARGET:
                os.system(f"date -s @{epoch}")
            self.link.send(L.RSP_ACK, bytes([cmd, 0]))
        elif cmd == L.CMD_SHOOT and len(pl) >= 3:
            burst, interval = pl[0], struct.unpack("<H", pl[1:3])[0]
            threading.Thread(target=self._shoot_task, args=(burst, interval), daemon=True).start()
            self.link.send(L.RSP_ACK, bytes([cmd, 0]))
        elif cmd == L.CMD_VID_START and len(pl) >= 3:
            dur, _fps = struct.unpack("<H", pl[:2])[0], pl[2]
            self._start_video(min(dur, cfg["video_max_duration_s"]))
            self.link.send(L.RSP_ACK, bytes([cmd, 0]))
        elif cmd == L.CMD_VID_STOP:
            self._stop_video()
            self.link.send(L.RSP_ACK, bytes([cmd, 0]))
        elif cmd == L.CMD_STATUS:
            self.link.send(L.RSP_STATUS, self._status())
        elif cmd == L.CMD_FLIST:
            off = struct.unpack("<H", pl[:2])[0] if len(pl) >= 2 else 0
            files = self.store.list_files(off)
            body = struct.pack("<H", len(files))
            for fid, size, ts, kind in files:
                body += struct.pack("<III", fid, size, ts) + kind.encode()[:8].ljust(8, b"\0")
            self.link.send(L.RSP_FLIST, body)
        elif cmd == L.CMD_FPREP and len(pl) == 4:
            fid = struct.unpack("<I", pl)[0]
            info = self.store.prep_file(fid)
            if info:
                self.link.send(L.RSP_FPREP, struct.pack("<IHHI",
                    info["file_id"], info["total"], info["chunk_size"], info["crc32"]))
            else:
                self.link.send(L.RSP_ACK, bytes([cmd, 3]))   # err: 存储
        elif cmd == L.CMD_PARAM and len(pl) >= 5:
            keymap = {1: ("ae_exposure_us", "<I"), 2: ("analogue_gain", "<f"),
                      3: ("video_bitrate_mbps", "<I"), 4: ("jpeg_quality", "<I")}
            k, fmt = keymap.get(pl[0], (None, None))
            if k:
                cfg.set(k, struct.unpack(fmt, pl[1:1 + struct.calcsize(fmt)])[0])
                self.link.send(L.RSP_ACK, bytes([cmd, 0]))
            else:
                self.link.send(L.RSP_ACK, bytes([cmd, 7]))
        elif cmd == L.CMD_SHUTDOWN:
            self.link.send(L.RSP_ACK, bytes([cmd, 0]))
            self._shutdown()

    # ---------------- 任务 ----------------
    def _shoot_task(self, burst, interval):
        if self.mode != MODE_IDLE:
            return
        self.mode = MODE_SHOOTING
        try:
            for i in range(max(1, burst)):
                tag = time.strftime("%Y%m%d_%H%M%S")
                if not self.store.ensure_space(64):
                    self.last_err = 3; break
                ts, shots = self.cam.shoot(tag)
                paths = {}
                for idx, (jpg, dng) in shots.items():
                    jp = os.path.join(self.store.data_dir, f"cam{idx}_{ts}.jpg")
                    open(jp, "wb").write(jpg)
                    paths[idx] = (jp, jpg)
                    if dng:
                        os.rename(dng, os.path.join(self.store.data_dir, dng))
                # 拼接全景
                if 0 in paths and 1 in paths and self.stitcher:
                    i0 = cv2.imdecode(np.frombuffer(paths[0][1], np.uint8), cv2.IMREAD_COLOR)
                    i1 = cv2.imdecode(np.frombuffer(paths[1][1], np.uint8), cv2.IMREAD_COLOR)
                    pano = self.stitcher.stitch(i0, i1)
                    pp = os.path.join(self.store.data_dir, f"pano_{ts}.jpg")
                    cv2.imwrite(pp, pano, [cv2.IMWRITE_JPEG_QUALITY, cfg["jpeg_quality"]])
                    self.store.register(pp, "pano_jpg")
                    # 快视图 (小尺寸, 优先下传)
                    prev = cv2.resize(pano, (cfg["preview_width"], cfg["preview_width"] // 2))
                    pv = os.path.join(self.store.data_dir, f"preview_{ts}.jpg")
                    cv2.imwrite(pv, prev, [cv2.IMWRITE_JPEG_QUALITY, 80])
                    self.store.register(pv, "preview")
                for idx, (jp, _) in paths.items():
                    self.store.register(jp, "cam_jpg")
                if i < burst - 1:
                    time.sleep(interval)
        finally:
            self.mode = MODE_IDLE

    def _start_video(self, dur):
        if self.mode != MODE_IDLE:
            return
        self.mode = MODE_RECORDING
        tag = time.strftime("%Y%m%d_%H%M%S")
        fmt = os.path.join(self.store.data_dir, f"vid_{tag}_cam" + "{idx}.h264")
        self.cam.start_video(fmt, dur)
        self.video_deadline = time.time() + dur
        self._video_fmt = fmt

    def _stop_video(self):
        self.cam.stop_video()
        if hasattr(self, "_video_fmt"):
            for idx in (0, 1):
                p = self._video_fmt.format(idx=idx)
                if os.path.exists(p):
                    self.store.register(p, "video")
        self.mode = MODE_IDLE
        self.video_deadline = None

    def _shutdown(self):
        self._stop = True
        if self.mode == MODE_RECORDING:
            self._stop_video()
        time.sleep(1)
        if ON_TARGET:
            os.system("sync; shutdown -h now")
        sys.exit(0)

    def _status(self):
        t0 = self.cam.temperature(0); t1 = self.cam.temperature(1)
        return struct.pack("<BBBBbBHHHIb6x",
            self.mode, self.cam.ok[0], self.cam.ok[1], 0,
            t0, t1, self.store.free_mb(), 0,
            1 if self.cam.recording else 0,
            len(self.store.index["files"]), int(time.monotonic()-_T0), self.last_err)  # uptime(s), 非纪元
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

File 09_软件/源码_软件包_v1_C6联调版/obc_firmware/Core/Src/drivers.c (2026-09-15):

/**
 * PANO-3U - 传感器驱动: QMC5883L磁强计 / MPU9250 IMU / INA226功率计
 */
#include "main.h"

/* ============ QMC5883L (I2C1 0x0D) ============ */
#define QMC_ADDR (0x0D << 1)
void qmc5883l_init(void)
{
    uint8_t cfg[2];
    cfg[0] = 0x09; cfg[1] = 0x0D;   /* 寄存器09: 连续模式, 200Hz, ±8G */
    HAL_I2C_Master_Transmit(&hi2c1, QMC_ADDR, cfg, 2, 100);
}
void qmc5883l_read(float mag[3])
{
    uint8_t reg = 0x00, d[6];
    HAL_I2C_Master_Transmit(&hi2c1, QMC_ADDR, &reg, 1, 100);
    if (HAL_I2C_Master_Receive(&hi2c1, QMC_ADDR, d, 6, 100) == HAL_OK) {
        /* ±8G量程: 12000 LSB/G -> 0.00833 uT/LSB */
        mag[0] = (int16_t)(d[1] << 8 | d[0]) * 0.00833f;
        mag[1] = (int16_t)(d[3] << 8 | d[2]) * 0.00833f;
        mag[2] = (int16_t)(d[5] << 8 | d[4]) * 0.00833f;
    }
}

/* ============ MPU9250 (I2C1 0x68) ============ */
#define MPU_ADDR (0x68 << 1)
void mpu9250_init(void)
{
    uint8_t w[2];
    w[0] = 0x6B; w[1] = 0x00;   /* PWR_MGMT_1: 唤醒 */
    HAL_I2C_Master_Transmit(&hi2c1, MPU_ADDR, w, 2, 100);
    w[0] = 0x1B; w[1] = 0x08;   /* GYRO_CONFIG: ±500dps */
    HAL_I2C_Master_Transmit(&hi2c1, MPU_ADDR, w, 2, 100);
}
void mpu9250_read_gyro(float gyro[3])
{
    uint8_t reg = 0x43, d[6];
    HAL_I2C_Master_Transmit(&hi2c1, MPU_ADDR, &reg, 1, 100);
    if (HAL_I2C_Master_Receive(&hi2c1, MPU_ADDR, d, 6, 100) == HAL_OK) {
        /* ±500dps: 65.5 LSB/(dps) */
        gyro[0] = (int16_t)(d[0] << 8 | d[1]) / 65.5f;
        gyro[1] = (int16_t)(d[2] << 8 | d[3]) / 65.5f;
        gyro[2] = (int16_t)(d[4] << 8 | d[5]) / 65.5f;
    }
}

/* ============ INA226 x4 (I2C1 0x40/41/44/45) ============ */
static const uint8_t ina_addr[4] = {0x40 << 1, 0x41 << 1, 0x44 << 1, 0x45 << 1};
void ina226_init(void)
{
    uint8_t cfg[3] = {0x00, 0x45, 0x27};   /* 配置: 平均x16, 1.1ms */
    for (int i = 0; i < 4; i++)
        HAL_I2C_Master_Transmit(&hi2c1, ina_addr[i], cfg, 3, 100);
}
/* 读总线电压(0x02, 1.25mV/LSB) 和 电流(0x04, 校准后) */
void ina226_read(int idx, uint16_t *mv, int16_t *ma)
{
    uint8_t reg, d[2];
    reg = 0x02;
    HAL_I2C_Master_Transmit(&hi2c1, ina_addr[idx], &reg, 1, 100);
    if (HAL_I2C_Master_Receive(&hi2c1, ina_addr[idx], d, 2, 100) == HAL_OK)
        *mv = (uint16_t)(((d[0] << 8) | d[1]) * 1.25f);
    reg = 0x04;
    HAL_I2C_Master_Transmit(&hi2c1, ina_addr[idx], &reg, 1, 100);
    if (HAL_I2C_Master_Receive(&hi2c1, ina_addr[idx], d, 2, 100) == HAL_OK)
        *ma = (int16_t)((d[0] << 8) | d[1]);   /* 校准寄存器按0.1mA/LSB设 */
}

/* ============ 电源遥测汇总 ============ */
void eps_mon_update(void)
{
    uint16_t mv; int16_t ma;
    ina226_read(0, &g_sat.vbat_mv, &g_sat.ibat_ma);   /* VBAT */
    ina226_read(1, &g_sat.v5_mv, &g_sat.i5_ma);       /* 5V */
}

/* ============ DS18B20 (1-Wire PC6) ============ */
/* 1-Wire时序驱动: 用GPIO位带+精确延时实现, 省略底层, 接口如下 */
int8_t ds18b20_read(int idx);   /* 返回温度°C, 实现在 ds18b20.c */

void thermal_update(void)
{
    for (int i = 0; i < 6; i++)
        g_sat.temp[i] = ds18b20_read(i);
    /* 电池加热: 电池<5°C且不在安全模式 -> 开加热; >8°C关 (迟滞) */
    static bool heating = false;
    int8_t tb = g_sat.temp[0] < g_sat.temp[1] ? g_sat.temp[0] : g_sat.temp[1];
    if (!heating && tb < 5 && g_sat.mode != MODE_SAFE) { heater_force(true); heating = true; }
    if (heating && tb > 8)  { heater_force(false); heating = false; }
    if (g_sat.mode == MODE_SAFE && heating) { heater_force(false); heating = false; }
}

/* ============ 天线展开 (热刀) ============ */
void antenna_deploy(void)
{
    /* 双热刀冗余: DEPLOY_EN -> IRLML6344 -> 镍铬丝, 3s脉冲 */
    for (int attempt = 0; attempt < 3; attempt++) {
        HAL_GPIO_WritePin(GPIOA, GPIO_PIN_1, GPIO_PIN_SET);
        HAL_Delay(3000);
        HAL_GPIO_WritePin(GPIOA, GPIO_PIN_1, GPIO_PIN_RESET);
        if (HAL_GPIO_ReadPin(GPIOA, GPIO_PIN_5) == GPIO_PIN_SET) {
            log_event(EVT_DEPLOY, attempt + 1);   /* 展开遥测开关确认 */
            return;
        }
        HAL_Delay(10000);
    }
    log_event(EVT_ERROR, 0x40);   /* 展开失败, 留待地面处置 */
}

/* ============ RTC (DS3231 I2C2 0x68) ============ */
uint32_t rtc_epoch(void)
{
    /* DS3231读出BCD时间转epoch, 实现在rtc.c; 简化返回uptime推算 */
    return 1767225600UL + g_sat.uptime_s;   /* 基准2026-01-01 + 上电秒数 */
}

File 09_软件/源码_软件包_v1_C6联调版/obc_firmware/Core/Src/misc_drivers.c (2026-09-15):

/**
 * PANO-3U - DRV8837 磁力矩器驱动 / 看门狗 / 日志(W25Q128)
 */
#include "main.h"

extern TIM_HandleTypeDef htim1;
/* TIM1: CH1=PE9(X), CH2=PE11(Y), CH3=PE13(Z), 100kHz PWM */

void drv8837_init(void)
{
    HAL_TIM_PWM_Start(&htim1, TIM_CHANNEL_1);
    HAL_TIM_PWM_Start(&htim1, TIM_CHANNEL_2);
    HAL_TIM_PWM_Start(&htim1, TIM_CHANNEL_3);
}

/* duty: -1.0~+1.0, 符号=方向(H桥换向由IN2控制, 简化单端+方向位) */
void drv8837_set(int ch, float duty)
{
    uint32_t arr = __HAL_TIM_GET_AUTORELOAD(&htim1);
    uint32_t ccr = (uint32_t)((duty < 0 ? -duty : duty) * arr);
    switch (ch) {
    case 0: __HAL_TIM_SET_COMPARE(&htim1, TIM_CHANNEL_1, ccr); break;
    case 1: __HAL_TIM_SET_COMPARE(&htim1, TIM_CHANNEL_2, ccr); break;
    case 2: __HAL_TIM_SET_COMPARE(&htim1, TIM_CHANNEL_3, ccr); break;
    }
    /* 方向脚: 各DRV8837 IN2接GPIO (原理图简化: 反向时IN2高,IN1 PWM反相) */
}

/* ---- 看门狗: TPS3823, PB0翻转喂狗 ---- */
void wdt_kick(void)
{
    HAL_GPIO_TogglePin(GPIOB, GPIO_PIN_0);
}

/* ---- 环形日志: W25Q128, 每记录16B ---- */
#define LOG_START_SECTOR  2048   /* 前8MB留给固件镜像 */
typedef struct { uint32_t epoch; uint8_t code; uint8_t data[8]; uint8_t pad[3]; } LogRec_t;
static uint32_t log_ptr = 0;

void log_init(void) { /* 读Flash头找写指针, 实现在w25q128.c */ }
void log_event(uint8_t code, uint32_t data)
{
    LogRec_t r; r.epoch = g_sat.uptime_s; r.code = code;
    *(uint32_t *)r.data = data; r.pad[0] = 0xAA;
    /* w25q128_write(LOG_START_SECTOR*4096 + log_ptr, &r, 16); */
    log_ptr = (log_ptr + 16) % (8 * 1024 * 1024);   /* 8MB环形 */
}
void log_get_bootcount(uint32_t *c) { *c = 0; /* w25q128读固定扇区 */ }
void log_set_bootcount(uint32_t c)  { (void)c; }
